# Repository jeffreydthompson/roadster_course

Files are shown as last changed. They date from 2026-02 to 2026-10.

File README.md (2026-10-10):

# Open Roadster

An open source remote control car — mechanical designs, circuit schematics, firmware, and software all in one place.

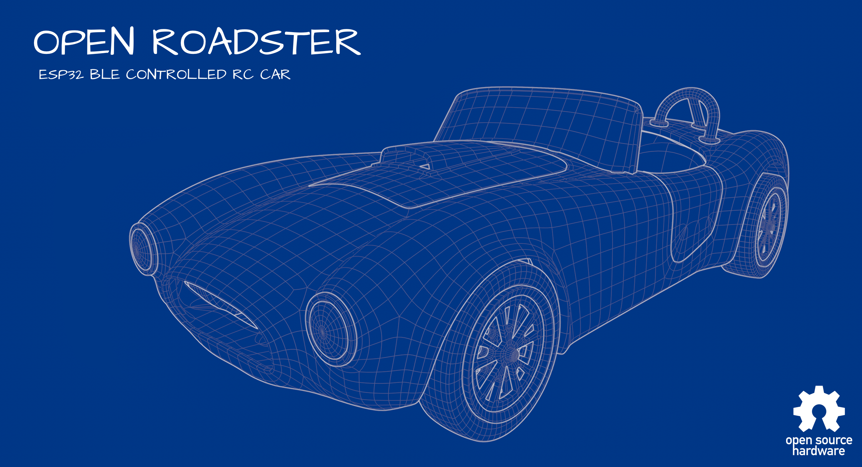
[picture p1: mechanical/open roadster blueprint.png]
Open Roadster Blueprint


## Overview

The Open Roadster is a fully open source RC car project covering every layer of the build:

- **Mechanical** — 3D-printable chassis and drivetrain in FreeCAD, body designed in Blender
- **Circuit** — custom 4-layer controller PCB designed in EasyEDA
- **Firmware** — ESP32-S3 motor, steering, and battery monitoring over Bluetooth LE
- **Software** — iOS remote control app (BLE)

## Repository Structure

```
├── mechanical/
│   ├── freecad/
│   │   ├── OpenRoadster.FCStd      # full chassis assembly, parts in position
│   │   ├── Printed Parts/          # one file per 3D-printed part
│   │   ├── Sheet Metal Parts/      # chassis base: model, flat-pattern DXF, bent STEP
│   │   └── Purchased Parts/        # motors, servo, bearing, screws, PCB
│   ├── stl/                        # ready-to-print STLs of the printed parts
│   ├── roadster.blend              # Blender body model
│   ├── open roadster blueprint.png
│   └── blueprints/                 # front, back, side, top views
├── code/
│   ├── app/ios/RoadsterRemote/     # iOS remote control app (SwiftUI + CoreBluetooth)
│   └── firmware/
│       ├── esp-flash.sh            # compile/upload helper (arduino-cli)
│       └── roadster_ctrl/          # main car firmware
└── circuits/
    ├── RCcar_schematic.pdf         # all schematic sheets
    ├── kicad/                      # KiCad 10 project (schematic + PCB), ported from EasyEDA
    ├── fabrication/                # Gerbers, BOM, pick-and-place for JLCPCB (from KiCad)
    └── easyeda/                    # original EasyEDA Standard source (schematic + PCB)
        └── fabrication/            # archived order files exported from EasyEDA
```

## Hardware

| Component | Details |
|---|---|
| Microcontroller | ESP32-S3 |
| Steering | Servo on GPIO 45 (333 Hz, 900–2100 µs, center 1520 µs) |
| Left drive motor | DRV8833 on GPIO 6 / 5 (sleep 11, fault 7) |
| Right drive motor | DRV8833 on GPIO 39 / 40 (sleep 38, fault 34) |
| Fuel gauge | MAX17048 over I2C (SDA 8, SCL 9) |
| Front light (headlights, `F.LED`) | GPIO 42, PWM |
| Rear light (tail / brake, `B.LED`) | GPIO 41, PWM |
| Power source (TPS2116 `ST`) | GPIO 26 — HIGH on USB power, LOW on battery |

All pins are defined at the top of `code/firmware/roadster_ctrl/roadster_ctrl.ino`. Motor direction is corrected in software with `setInverted(true)` in the same file — if a wheel spins the wrong way, that's the line to change.

## Getting Started

### Firmware

1. Install [arduino-cli](https://arduino.github.io/arduino-cli/) (or the [Arduino IDE](https://www.arduino.cc/en/software))
2. Install the ESP32 board support (`esp32:esp32`, tested with 3.3.x)
3. Install the libraries: `arduino-cli lib install ESP32Servo "Adafruit MAX1704X"`
4. Compile and upload:

```sh
cd code/firmware
./esp-flash.sh compile roadster_ctrl
./esp-flash.sh upload roadster_ctrl /dev/cu.usbmodem1101   # your port; see `arduino-cli board list`
```

The board target is set at the top of `esp-flash.sh` (`esp32:esp32:esp32s3`). If you use the Arduino IDE instead, open `code/firmware/roadster_ctrl/roadster_ctrl.ino` and select an ESP32S3 board.

### Driving the car

The car advertises over Bluetooth LE as `Open Roadster` and exposes two services:

| Service | UUID | Purpose |
|---|---|---|
| Nordic UART | `6E400001-B5A3-F393-E0A9-E50E24DCCA9E` | Control |
| ↳ RX (write) | `6E400002-B5A3-F393-E0A9-E50E24DCCA9E` | Control packets / commands |
| ↳ TX (notify) | `6E400003-B5A3-F393-E0A9-E50E24DCCA9E` | Feedback for single-character commands |
| Battery | `180F` | Standard Bluetooth battery service |
| ↳ Battery Level | `2A19` | 0–100 %, from the MAX17048 |
| ↳ Power Source | `8FDDF80E-8D10-4B50-9466-FCE56AF3B124` | 1 = on USB power (battery charging), 0 = on battery; notifies on change |

**Control packet** (what the iOS app sends) — 5 bytes, little-endian:

| Bytes | Type | Field | Range |
|---|---|---|---|
| 0–1 | `int16` | steering | -100 (left) … 100 (right) |
| 2–3 | `int16` | throttle | -255 (reverse) … 255 (forward) |
| 4 | `uint8` | headlight | 0 = off, 1 = on |

**Single-character commands** — writing one byte to RX also works, which makes it easy to test with a generic BLE UART app (nRF Connect, Bluefruit Connect):

| Command | Action |
|---|---|
| `f` | Forward, full speed |
| `b` | Backward, 25% speed |
| `s` | Stop |
| `l` / `r` / `c` | Steer left / right / center |

The same commands work over USB serial (115200 baud) when `ENABLE_SERIAL` is set to `true` in `roadster_ctrl.ino` (it is off by default).

As a safety failsafe, the motors stop automatically if the Bluetooth connection drops.

**Lights:** the headlight flag in the control packet turns on the front light, and the rear light glows as a tail light. The rear light goes to full brightness as a brake light when the throttle is released or drops sharply (held for 0.8 s), and stays on while reversing. Brightness levels and timing are constants at the top of `LightsModule.h`.

### iOS App

1. Open `code/app/ios/RoadsterRemote/RoadsterRemote.xcodeproj` in Xcode
2. In the project settings, under **Signing & Capabilities**, select your own **Team** (or create a free Apple Developer account)
3. Change the **Bundle Identifier** to one of your own (e.g., `com.yourname.RoadsterRemote`). Bundle IDs are unique per Apple account, so the default `org.openroadster.RoadsterRemote` may already be taken
4. Build and run on your device

On launch the app scans for nearby cars and lists every Open Roadster in range with its signal strength. Tap one to connect. Tap the connection indicator any time to switch cars or disconnect. The app drops back to Park whenever the connection is lost.

### Circuit board

The controller is a 4-layer, 60 × 40 mm board built around an **ESP32-S3-MINI-1-N8**. On board:

| Function | Part |
|---|---|
| Microcontroller (Wi-Fi + BLE) | ESP32-S3-MINI-1-N8 |
| Motor drivers (one per rear wheel) | 2× DRV8833 |
| Battery charger (single-cell LiPo, via USB-C) | MCP73831 |
| Fuel gauge | MAX17048 |
| 3.3 V supply (buck-boost) | TPS63001 |
| USB / battery power switchover | TPS2116 |
| USB-to-serial for programming | CP2102N |
| Connectors | USB-C, battery (PH2.0), 2× motor, servo, front + rear LED |

Files in `circuits/`:

- `RCcar_schematic.pdf` — the full schematic (Sheet 1, Power, Motor Control, LED Drivers, USB Programmer); no software needed
- `kicad/` — the full design as a [KiCad](https://www.kicad.org/) 10 project; open `RCcar.kicad_pro` (see notes below)
- `fabrication/` — **the files to order with**, generated from the KiCad project in JLCPCB's format: `RCcar_kicad_gerber.zip`, `RCcar_bom_jlcpcb.csv`, `RCcar_cpl_jlcpcb.csv`
- `easyeda/` — the original EasyEDA Standard source. In EasyEDA, use **File → Open → EasyEDA Source** to open `RCcar_schematic.json` and `RCcar_pcb.json`
- `easyeda/fabrication/` — archived order files exported from EasyEDA (`RCcar_gerber.zip`, `RCcar_bom.csv`, `RCcar_pick_and_place.csv`), kept for reference

The board passes EasyEDA's design rule check with no errors, and all nets are routed.

**About the KiCad port.** The KiCad project was imported from the EasyEDA source and checked against it:

- Schematic and board agree on every connection (KiCad's schematic parity check finds no split or merged nets; remaining parity notes are naming differences from the import).
- Design rules match EasyEDA's (0.152 mm minimum clearance, 0.254 mm tracks); DRC reports no clearance errors and no unconnected items.
- KiCad fills copper pours slightly differently from EasyEDA, so 14 short tracks (0.2 mm) were added where KiCad's fill couldn't reach a few fine-pitch pins that EasyEDA's pour connected (around U1, U3, U5, U6, U7 and R2).
- KiCad's Gerbers match EasyEDA's copper to within about 1% per layer; the differences are pour edges and thermal spokes around pads.
- The project is self-contained: all symbols and footprints live in project libraries (`RCcar.kicad_sym`, `RCcar.pretty/`), registered in the project's `sym-lib-table` and `fp-lib-table`.
- Remaining DRC/ERC items are left visible on purpose. They are cosmetic or come from the import: courtyard overlaps from the tight placement, EasyEDA silkscreen touching pads, footprints that differ from their library copy by rounding or 3D model, and EasyEDA symbols whose pin types trigger "not driven" and pin-type warnings.
- 3D models aren't included yet; the 3D viewer will show bare footprints.

**Ordering from JLCPCB.** Upload the Gerber zip for bare boards (4 layers, 60 × 40 mm). For assembly, add the BOM and CPL (pick-and-place) files; every part has an LCSC part number. Parts are on both sides, so choose two-sided assembly. Always check part rotations in JLCPCB's assembly preview before paying.

The KiCad order files were checked against the EasyEDA ones: the same 91 parts with the same LCSC numbers, identical positions, sides and rotations, and copper within about 1% per layer (pour edges). KiCad also opens the solder mask around the bare mounting and locating holes. The EasyEDA set is what the original boards were made from. The KiCad set in `fabrication/` is the one to use; KiCad is now where the design is maintained.

### Mechanical

**Chassis, steering, and wheels** are in [FreeCAD](https://www.freecad.org/) (1.0 or newer) under `mechanical/freecad/`:

- `OpenRoadster.FCStd` — the complete chassis assembly with every part in position
- `Printed Parts/` — one file per printed part, for editing. Ready-to-print STLs are in `mechanical/stl/` (exported at 0.01 mm tolerance, in mm)
- `Sheet Metal Parts/` — the chassis base, made by a sheet metal shop rather than printed (see below)
- `Purchased Parts/` — models of the off-the-shelf components, for fit checks

| Purchased part | Qty |
|---|---|
| N20 DC gear motor (`or.n20.dc.motor`) | 2 |
| D1802MG micro servo (`or.d1802mg.servo`) | 1 |
| Front wheel bearing (`or.bearing.front`) | 2 |
| Hub screw (`or.hubscrew`) | 4 |
| Controller PCB (`PCB`) | 1 |

**Sheet metal chassis base** (`or.sheetmetal.base`) — 0.8 mm steel, flat blank 100.6 × 167.0 mm, 9 bends. Send a fabrication service (SendCutSend, OSH Cut, JLCCNC, etc.) both files:

- `or.sheetmetal.base.flat.dxf` — flat pattern in mm; outline and holes on layer `CUT`, bend lines on layer `BEND`
- `or.sheetmetal.base.step` — the bent part, so the shop can confirm bend directions and angles

The parts were converted from the original Onshape model as solid bodies, so they don't carry the parametric feature history. They can be measured, modified, and re-exported, but not edited by changing the original sketches.

**Body:** open `mechanical/roadster.blend` in [Blender](https://www.blender.org/) and export STL files for printing. Refer to the blueprints for assembly dimensions.

## License

- Code (`code/`) — [MIT](LICENSE)
- Hardware and mechanical designs (`mechanical/`, `circuits/`) — [CC BY 4.0](https://creativecommons.org/licenses/by/4.0/)

See [LICENSE](LICENSE) for details.

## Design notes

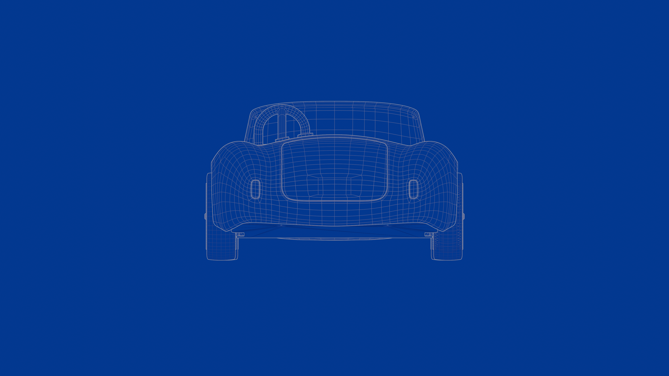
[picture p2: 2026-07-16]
mechanical/blueprints/back.png

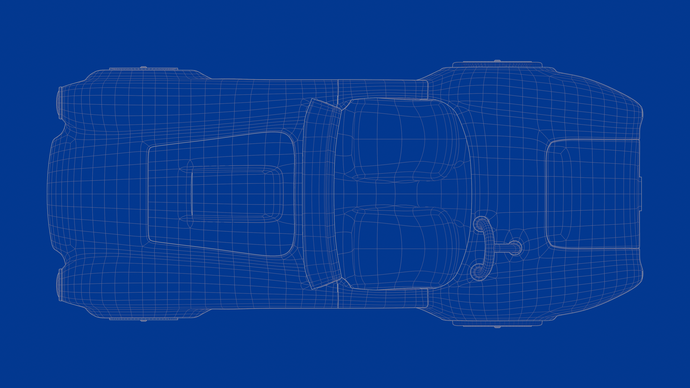
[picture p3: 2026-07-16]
mechanical/blueprints/top.png

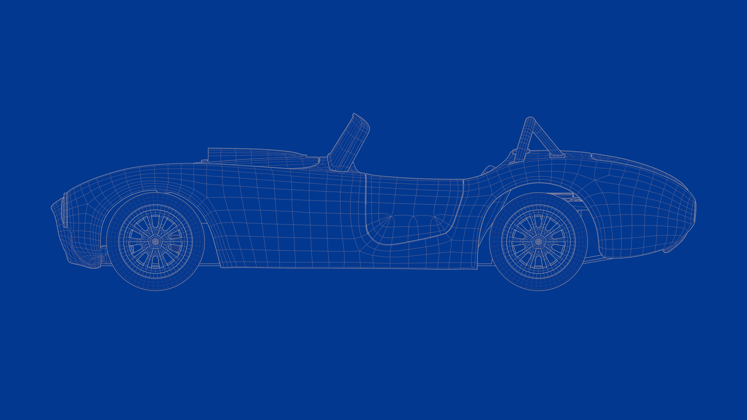
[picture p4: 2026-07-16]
mechanical/blueprints/side.png

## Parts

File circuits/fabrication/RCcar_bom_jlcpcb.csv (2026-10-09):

Comment | Designator | Footprint | LCSC Part #
SM02B-SRSS-TB (LF)(SN) | B.LED,F.LED | CONN-SMD_2P-P1.00_SM02B-SRSS-TB-LF-SN | C160402
PH2.0-2PWB | BATTERY | CONN-SMD_2P-P2.00_PH2.0-SPWB | C47647
TS-1088-AR02016 | BOOT,EN | SW-SMD_L3.9-W3.0-P4.45 | C720477
4.7uF | C1 | C0402 | C23733
22uF | C2 | C0805 | C45783
4.7uF | C3,C4 | C0805 | C1779
22uF | C5,C25,C34 | C1206 | C7472972
100nF | C6,C18,C20,C22,C23 | C0402_NEW | C1525
10uF | C7,C8,C9 | C0603 | C3039698
100nF | C10 | C0402_v2 | C1525
100nF | C11,C27,C32 | C0603 | C66501
2.2uF | C26,C33 | C0603 | C100082
10nF | C28,C31 | C0603 | C519406
100nF | C29,C30 | C0603 | C14663
0805G (Green) | CHARGED | LED0805-R-RD | C2297
17-21SUYC/TR8 | CHARGING | LED0805-R-RD | C2296
SP0503BAHTG | D3 | SOT-143_L2.9-W1.3-P1.92-LS2.3-BR | C7074
S2B-ZR-SM4A-TF(LF)(SN) | L.MOTOR,R.MOTOR | CONN-SMD_S2B-ZR-SM4A | C265329
2.2uH | L1 | IND-SMD_L3.0-W3.0_FNR30XXS | C370424
FC-2012HRK-620D | POWER | LED0805-R-RD | C84256
SI2305CDS | Q1 | SOT-23-3_L2.9-W1.6-P1.90-LS2.8-BR | C5182095
2SC2712-GR,LF(T | Q3,Q4,Q7,Q8 | SOT-23-3_L2.9-W1.6-P1.90-LS2.8-BR | C83447
SS8050-G | Q10,Q11 | SOT-23-3_L2.9-W1.6-P1.90-LS2.8-BR | C164886
5.1kΩ | R1,R5,R6,R9 | R0402 | C25905
10kΩ | R2,R3,R8,R14,R16,R19,R37,R38,R41 | R0402 | C25744
100Ω | R4 | R0402 | C25076
470Ω | R7,R10,R11 | R0603 | C23179
4.7kΩ | R12,R13 | R0402 | C25900
100Ω | R15,R17,R18,R20 | R0402 | C106232
22Ω | R21,R23 | R0603 | C23345
1kΩ | R22,R24 | R0603 | C161809
100kΩ | R25 | R0603 | C25803
1kΩ | R31 | R0402 | C11702
47.5kΩ | R32 | R0402 | C25896
22.1kΩ | R33 | R0402 | C43473
22Ω | R35 | R0402 | C25092
0Ω | R39,R40 | R0402 | C17168
HCZZ0323-3 | SERVO | CONN-SMD_3P-P1.50_HCZZ0323-3 | C7433559
MS-12D08G3.5 | SW2 | SW-TH_MS-12D08G3.5 | C2939255
ESP32-S3-MINI-1-N8 | U1 | BULETM-SMD_ESP32-S3-MINI-1-N8 | C2913206
TPS2116DRLR | U3 | SOT-583-8_L2.1-W1.6-P0.50-LS1.6-BL | C3235557
50mΩ | U4,U11 | R1206 | C7467249
TPS63001DRCR | U5 | VSON-10_L3.0-W3.0-P0.50-TL-EP_TPS62410DRCR | C28060
CP2102N-A02-GQFN28R | U6 | QFN-28_L5.0-W5.0-P0.50-TL-EP3.3 | C964632
MAX17048G+T10 | U7 | TDFN-8_L2.0-W2.0-P0.50-BL-EP1.2 | C2682616
DRV8833RTYR | U8,U10 | QFN-16_L4.0-W4.0-P0.65-TL-EP2.6 | C154936
MCP73831T-2ACI/OT | U9 | SOT-23-5_L3.0-W1.7-P0.95-LS2.8-BR | C424093
TYPE-C 16PIN 2MD(073) | USB | USB-C-SMD_TYPE-C-6PIN-2MD-073 | C2765186

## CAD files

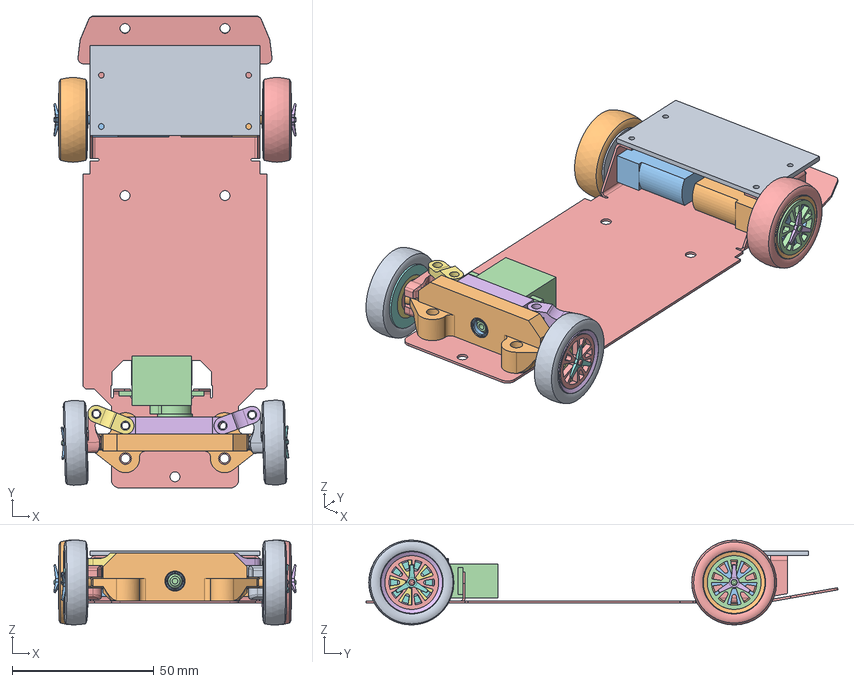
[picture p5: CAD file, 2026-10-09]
mechanical/freecad/OpenRoadster.FCStd
85.4 x 166.7 x 30.0 mm
PCB
or.n20.dc.motor
or.n20.dc.motor001
or.d1802mg.servo
or.sheetmetal.base
or.linkage.rack
or.bearing.front
or.bearing.front001
or.steeringknuckle.left
or.linkage.frame
or.pinion.bushing
or.linkage.pinion
or.steeringknuckle.right
or.linkage.arm
or.linkage.arm001
or.rim.front
or.tire.front
or.hub.front
or.hubscrew
or.hubcap
or.hubcap001
or.rim.front001
or.hub.front001
or.hubscrew001
or.tire.front001
or.rim.rear
or.hub.rear
or.hubcap002
or.tire.rear
or.hubscrew002
or.hub.rear001
or.hubcap003
or.rim.rear001
or.tire.rear001
or.hubscrew003

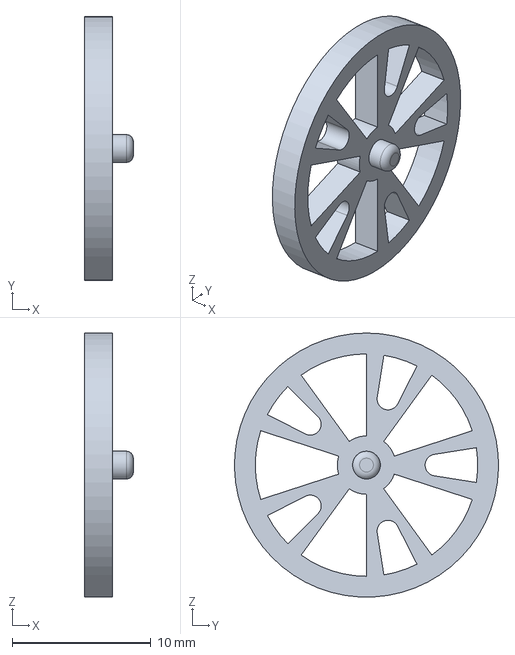
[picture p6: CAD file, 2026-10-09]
mechanical/freecad/Printed Parts/or.hubcap.FCStd
3.50 x 19.0 x 19.0 mm

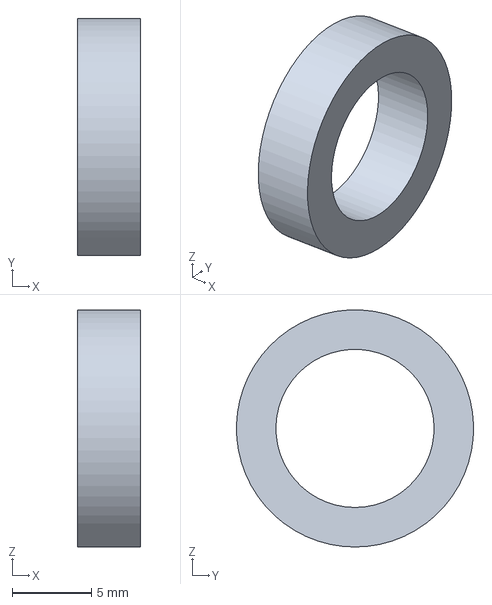
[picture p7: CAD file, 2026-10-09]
mechanical/freecad/Purchased Parts/or.bearing.front.FCStd
4.00 x 15.0 x 15.0 mm

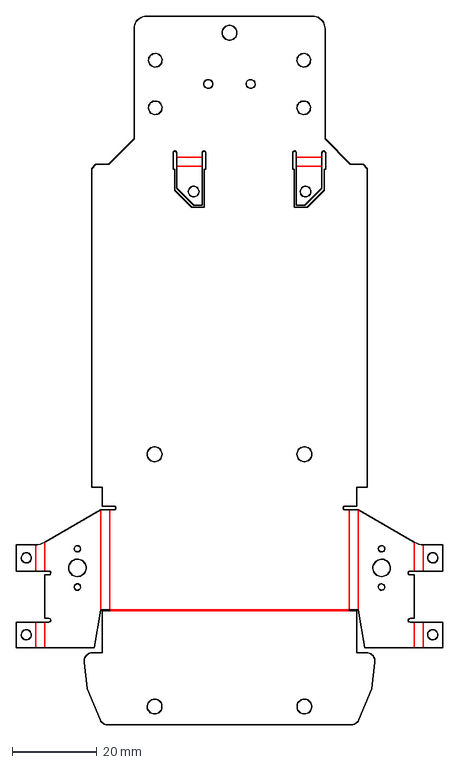
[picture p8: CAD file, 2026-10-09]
mechanical/freecad/Sheet Metal Parts/or.sheetmetal.base.flat.dxf
100.5 x 167.0 mm

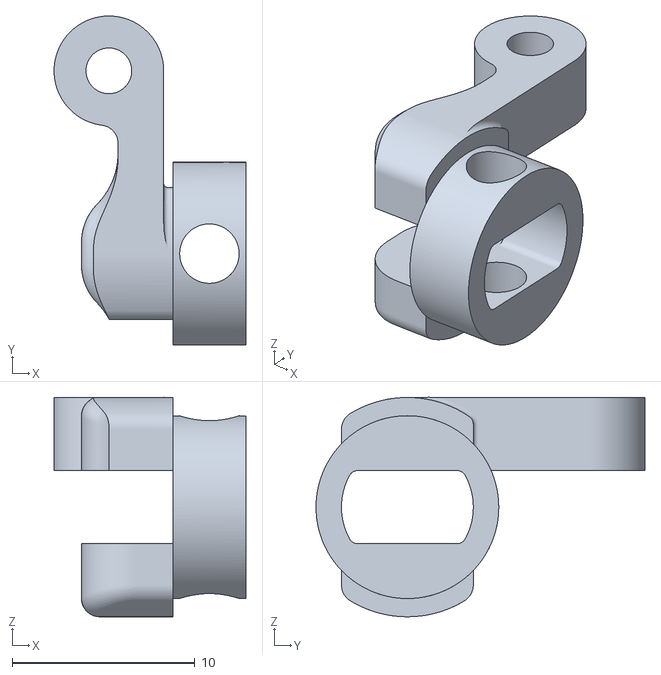
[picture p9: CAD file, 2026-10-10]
mechanical/stl/or.steeringknuckle.left.stl
10.5 x 18.0 x 12.0

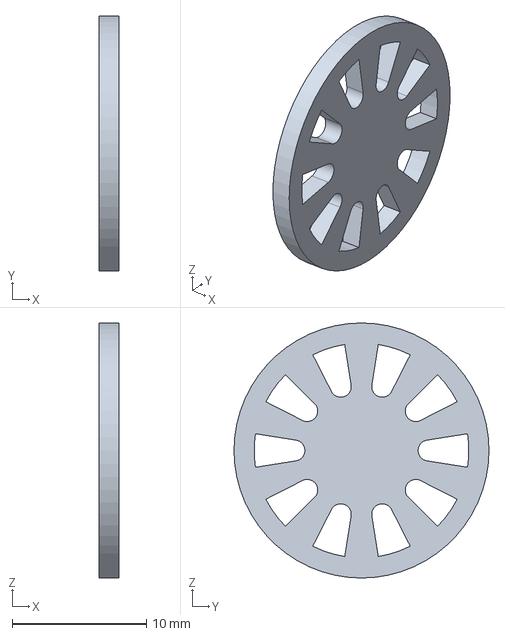
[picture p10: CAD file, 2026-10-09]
mechanical/freecad/Printed Parts/or.hub.front.FCStd
1.50 x 19.0 x 19.0 mm

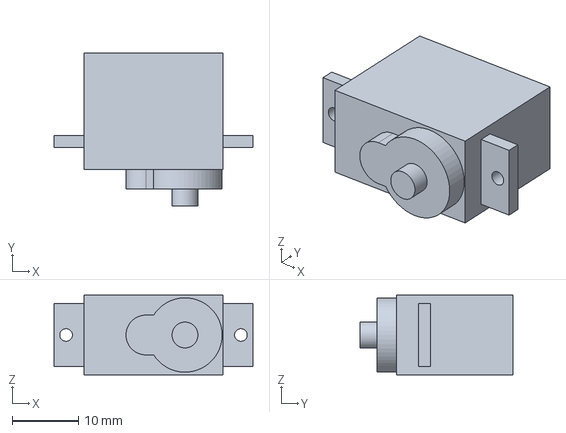
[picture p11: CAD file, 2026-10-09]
mechanical/freecad/Purchased Parts/or.d1802mg.servo.FCStd
30.0 x 23.0 x 12.0 mm

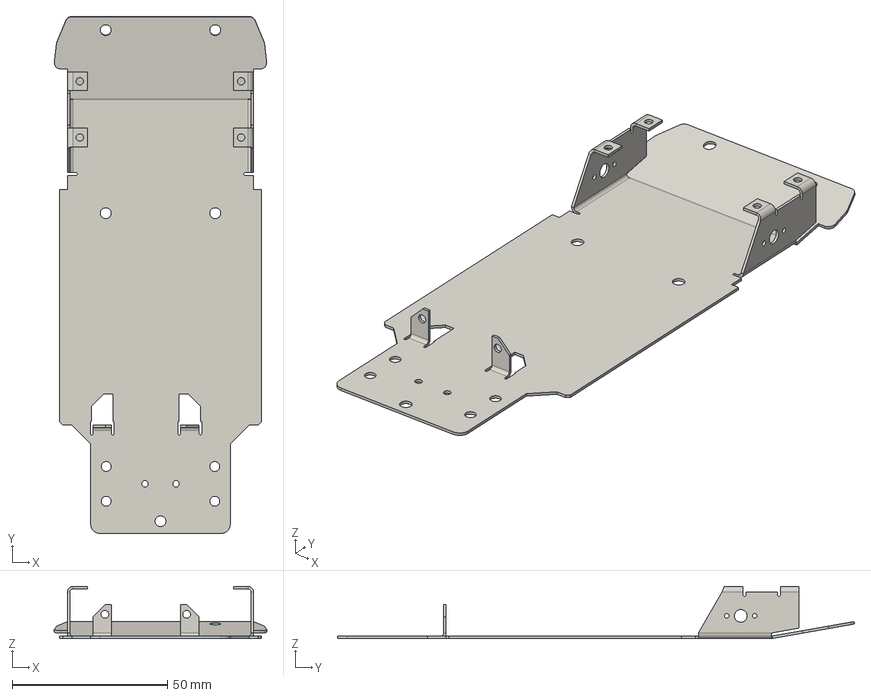
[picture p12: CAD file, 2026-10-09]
mechanical/freecad/Sheet Metal Parts/or.sheetmetal.base.step
68.5 x 166.7 x 16.8 mm

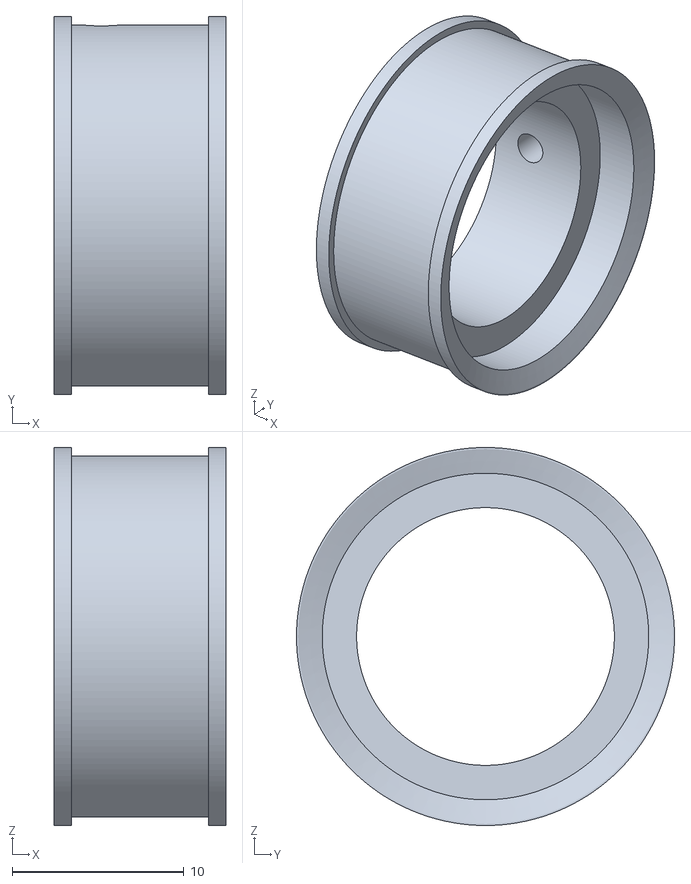
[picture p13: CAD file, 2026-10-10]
mechanical/stl/or.rim.rear.stl
10.0 x 22.0 x 22.0

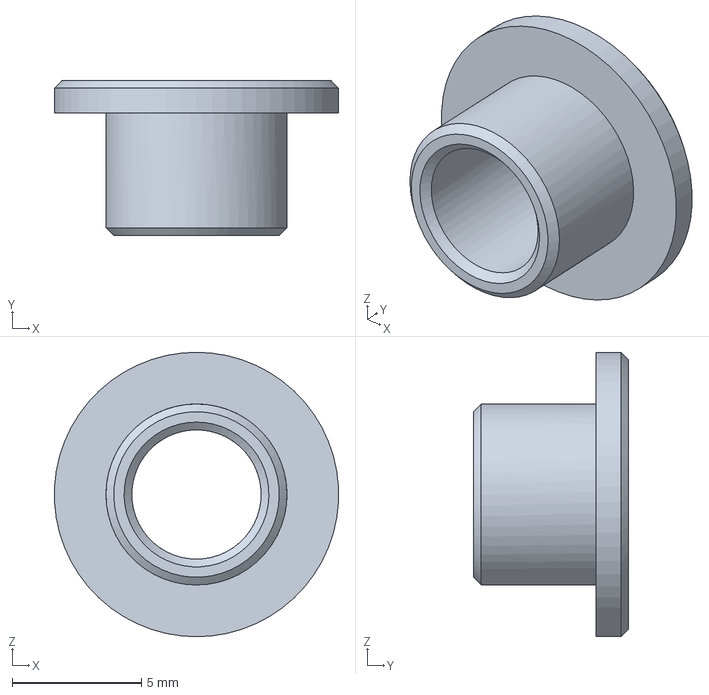
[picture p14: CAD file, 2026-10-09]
mechanical/freecad/Printed Parts/or.pinion.bushing.FCStd
11.0 x 6.00 x 11.0 mm

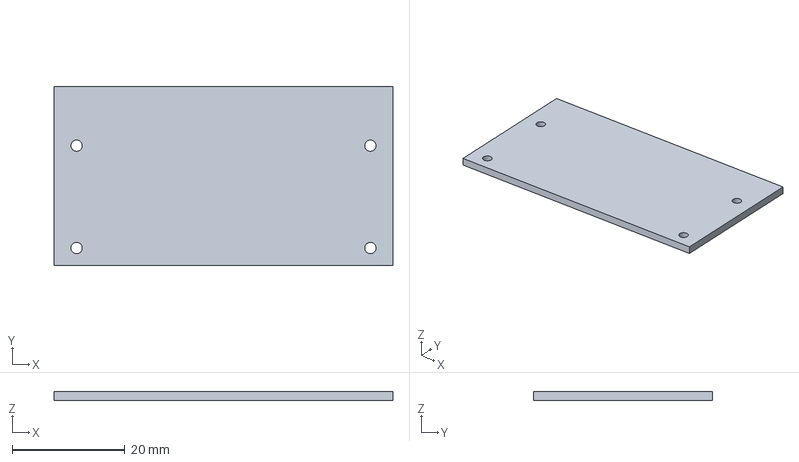
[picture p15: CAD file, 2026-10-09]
mechanical/freecad/Purchased Parts/PCB.FCStd
60.0 x 31.7 x 1.60 mm

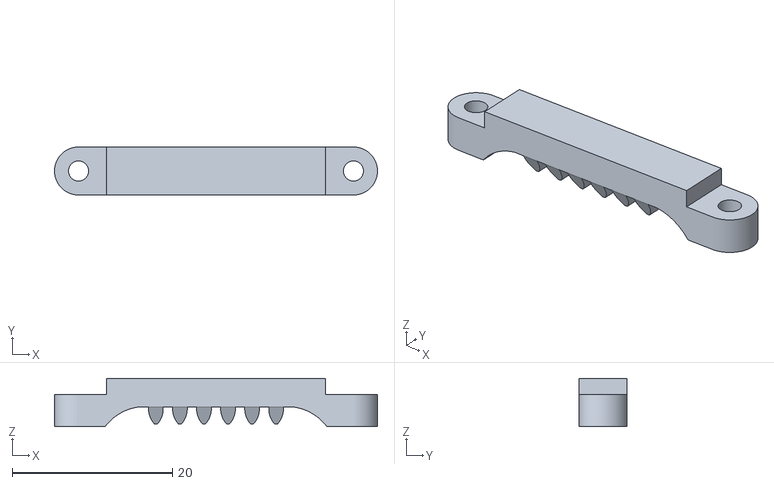
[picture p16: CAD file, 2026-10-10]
mechanical/stl/or.linkage.rack.stl
40.3 x 6.00 x 6.00

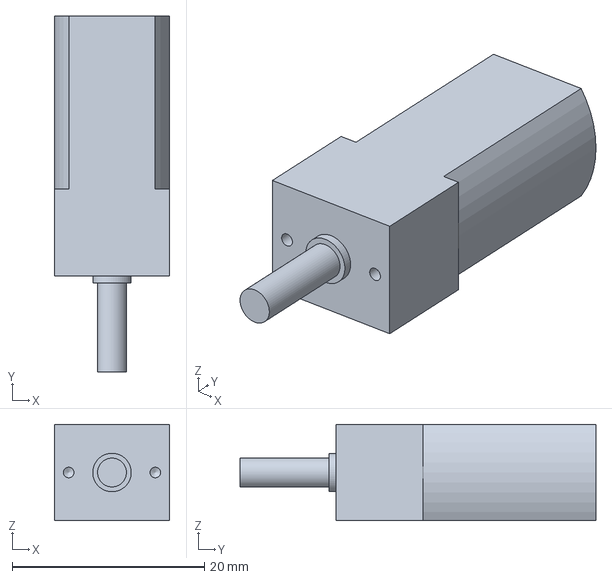
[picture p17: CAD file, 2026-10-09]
mechanical/freecad/Purchased Parts/or.n20.dc.motor.FCStd
12.0 x 37.0 x 10.0 mm

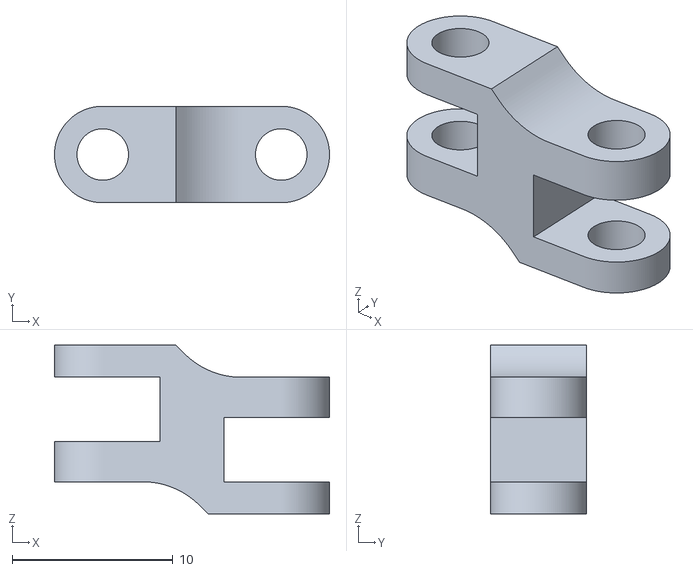
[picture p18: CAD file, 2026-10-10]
mechanical/stl/or.linkage.arm.stl
17.1 x 6.00 x 10.5

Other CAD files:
mechanical/freecad/Printed Parts/or.linkage.rack.FCStd
mechanical/freecad/Printed Parts/or.linkage.arm.FCStd
mechanical/stl/or.linkage.frame.stl
mechanical/freecad/Printed Parts/or.rim.rear.FCStd
mechanical/freecad/Printed Parts/or.hub.rear.FCStd
mechanical/freecad/Printed Parts/or.linkage.frame.FCStd
mechanical/freecad/Printed Parts/or.linkage.pinion.FCStd
mechanical/freecad/Printed Parts/or.rim.front.FCStd
mechanical/freecad/Printed Parts/or.steeringknuckle.left.FCStd
mechanical/freecad/Printed Parts/or.steeringknuckle.right.FCStd
mechanical/freecad/Printed Parts/or.tire.front.FCStd
mechanical/freecad/Printed Parts/or.tire.rear.FCStd
mechanical/freecad/Purchased Parts/or.hubscrew.FCStd
mechanical/freecad/Sheet Metal Parts/or.sheetmetal.base.FCStd
mechanical/roadster.blend
mechanical/stl/or.hub.front.stl
mechanical/stl/or.hub.rear.stl
mechanical/stl/or.hubcap.stl
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

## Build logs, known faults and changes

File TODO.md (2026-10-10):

# TODO

## Battery protection

A pack left with the power switch on drains until the buck-boost gives up
(about 1.8 V), which kills the cell. Nothing on the Rev 2 board stops this.

### Firmware (Rev 2 boards)

- [ ] Low-battery cutoff: poll the MAX17048 cell voltage (already read every
      2 s in `BatteryModule`).
  - Below ~3.3 V under load: stop the motors and flash the lights as a warning.
  - Below ~3.2 V: stop the motors and put the ESP32 into deep sleep.
  - This is only partial protection. The servo, fuel gauge, regulator and
    motor drivers stay powered in sleep (estimated 1–5 mA, not yet measured),
    so it buys days, not months.
- [ ] Measure the actual idle current with the switch on (advertising, and in
      deep sleep) to know how long a forgotten car lasts.
- [ ] Report cell voltage over BLE alongside the percentage, since the
      MAX17048 % is unreliable until it has seen a charge/discharge cycle.

### Hardware (Rev 3 board)

- [ ] Add a battery protection IC (e.g. DW01A + FS8205A) between the
      BATTERY connector and VBATT, for hardware over-discharge, over-charge
      and short-circuit cutoff.
- [ ] Connect MAX17048 ALRT# to a GPIO (it's unconnected on Rev 2) so a low
      battery alert can wake the ESP32.
- [ ] Consider letting the ESP32 shut off the TPS63001 (its EN is currently
      tied to VIN through R4) or switch the servo supply, so firmware can do
      a real cutoff.

The power switch (SW2) itself is fine. It disconnects everything except the
MCP73831's VBAT pin (~0.25 µA) and the reverse-polarity FET, and charging
still works with it off.

## App / firmware

- [ ] Throttle range mismatch: the iOS app sends 0..100 with no reverse,
      the firmware expects −255..255. App full throttle is only ~40%.

## PCB (KiCad)

- [ ] Remaining DRC items: courtyard overlaps, CHARGED/CHARGING silk over SW2.
- [ ] 3D models for the footprints.

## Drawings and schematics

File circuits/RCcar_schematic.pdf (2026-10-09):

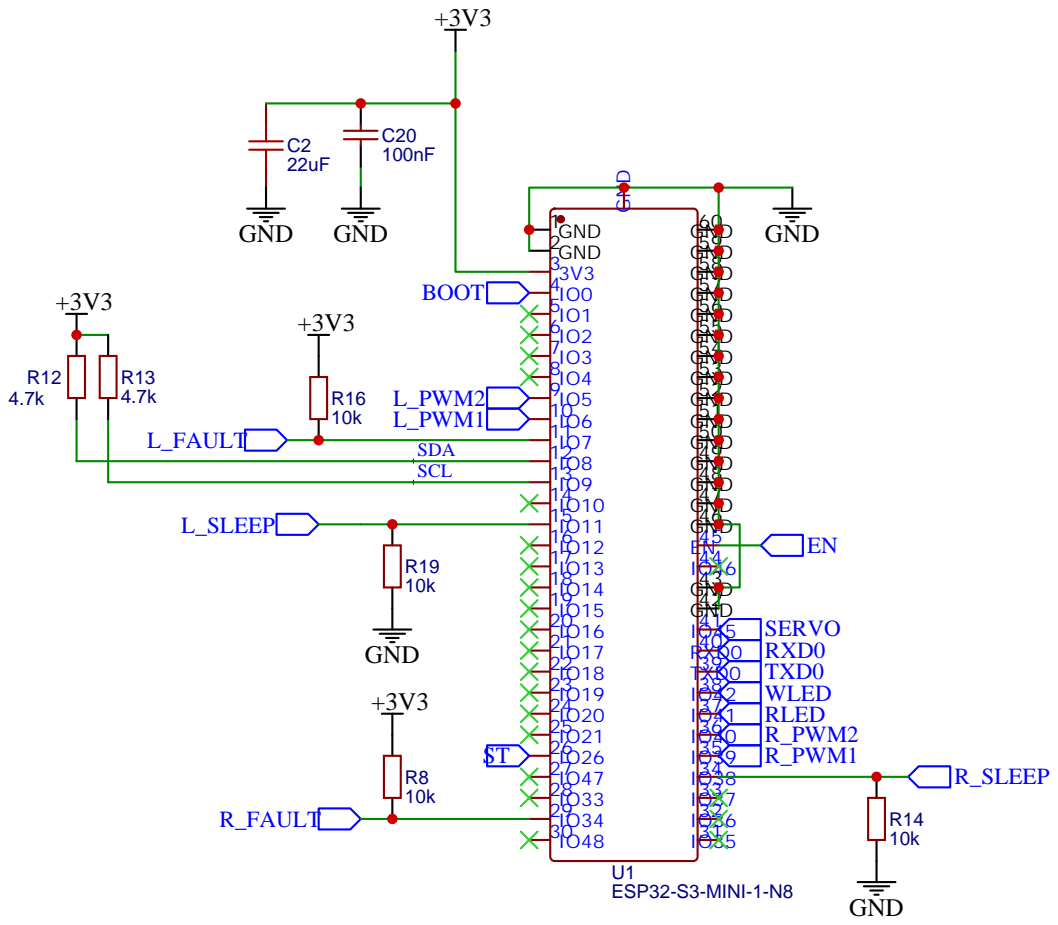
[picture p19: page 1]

Drawn By: Jeffrey Thompson

# CHARGE

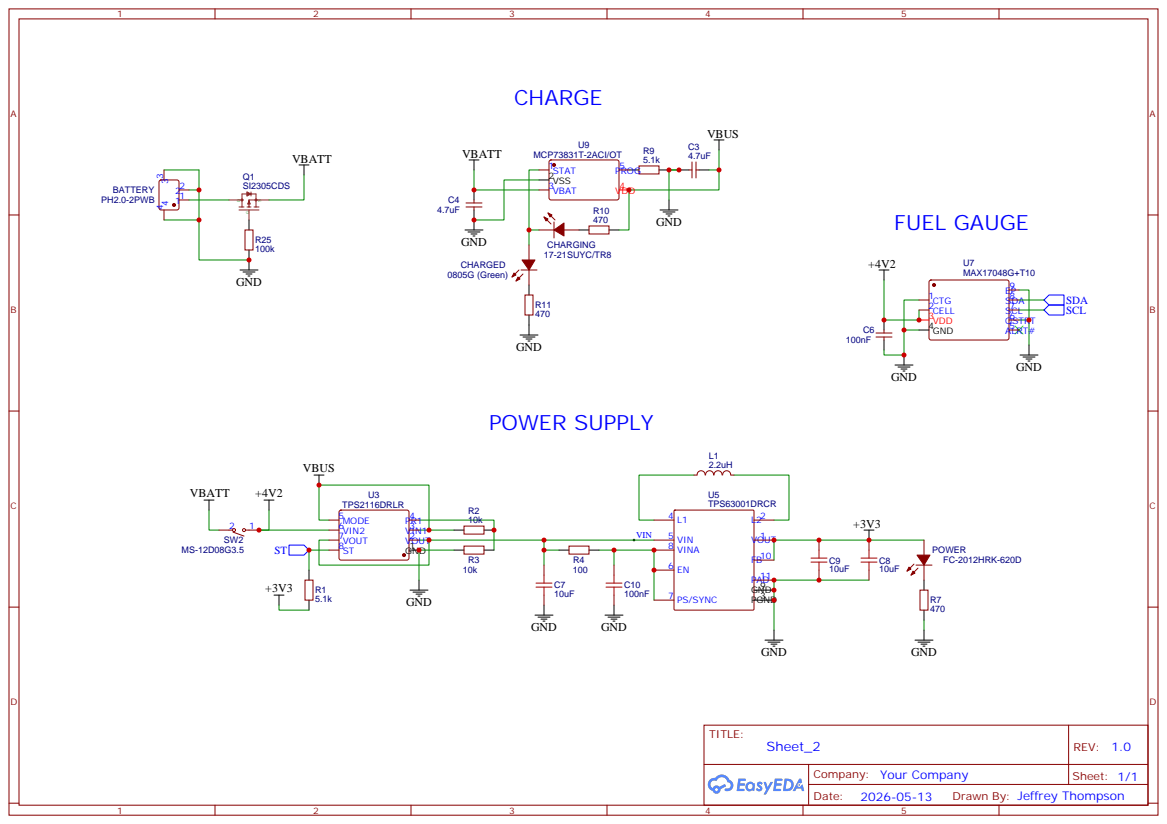
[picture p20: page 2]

# L MOTOR

# VM10 GND 11 VINT 12 AIN2 13 AIN1 14 nSLEEP 15 AOUT1 16 GND 17

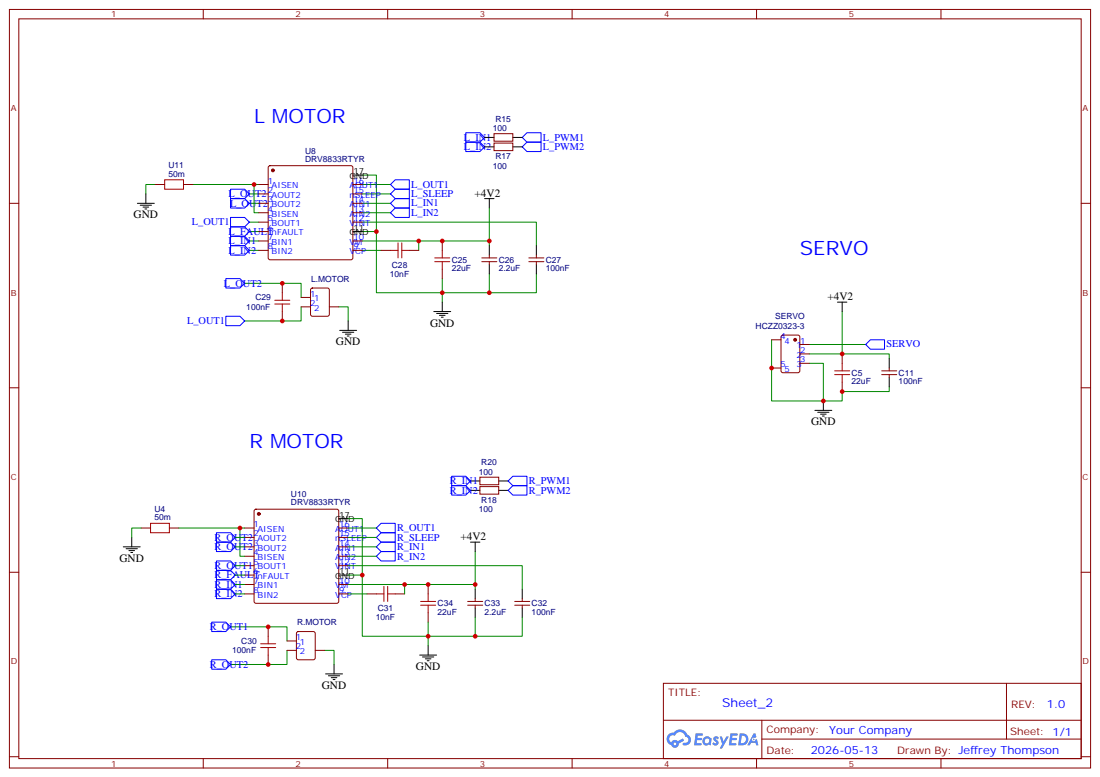
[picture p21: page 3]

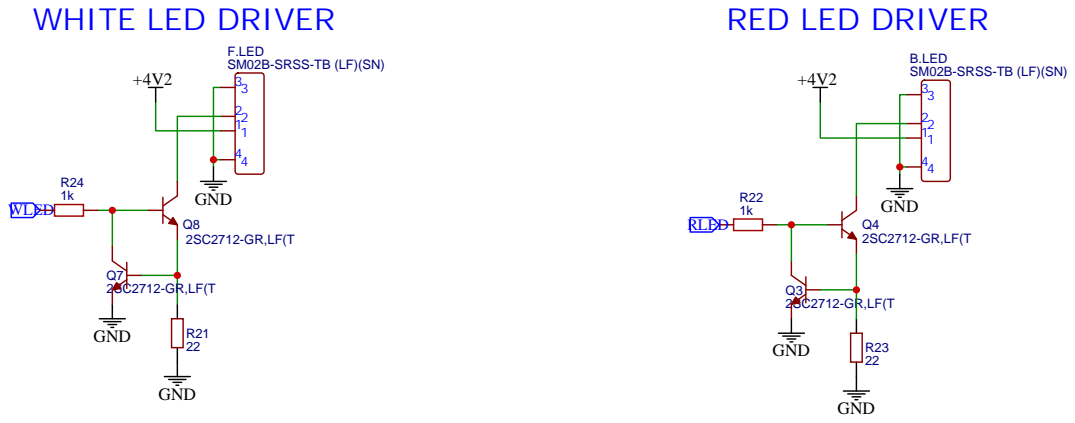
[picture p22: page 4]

# USB TO SERIAL CONVERTER

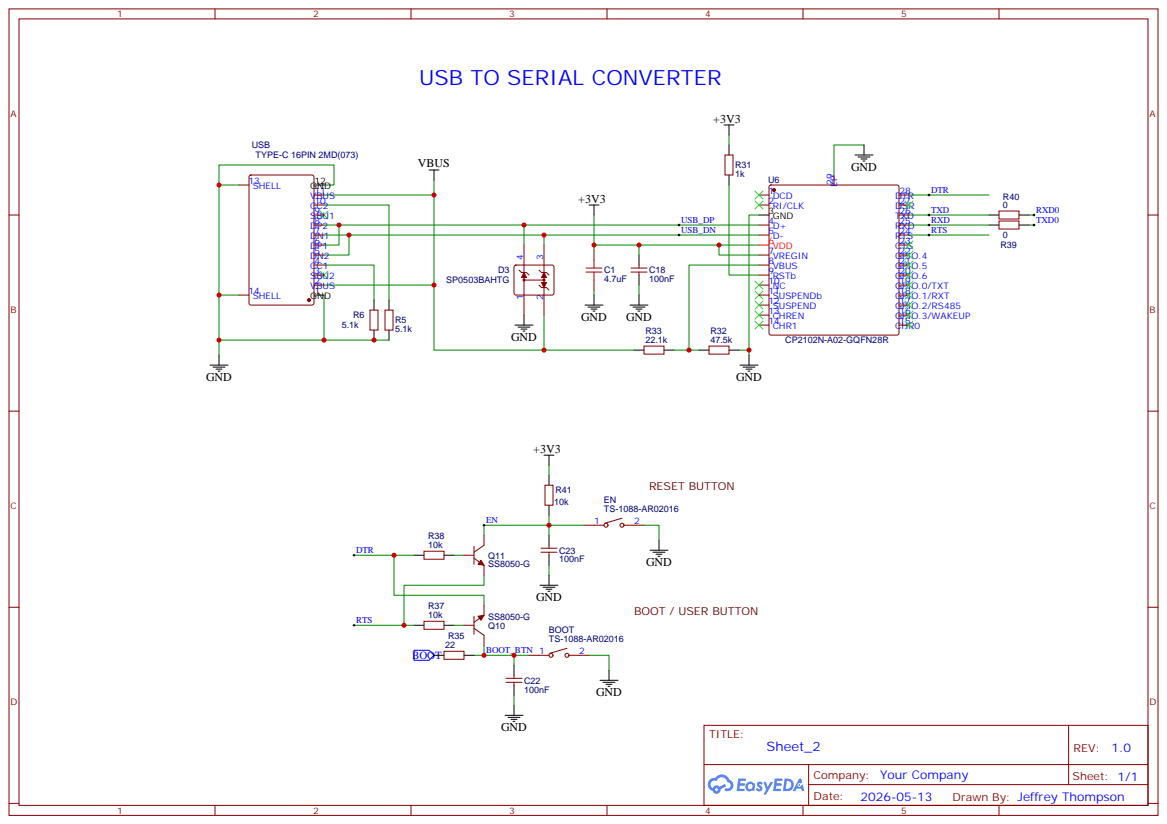
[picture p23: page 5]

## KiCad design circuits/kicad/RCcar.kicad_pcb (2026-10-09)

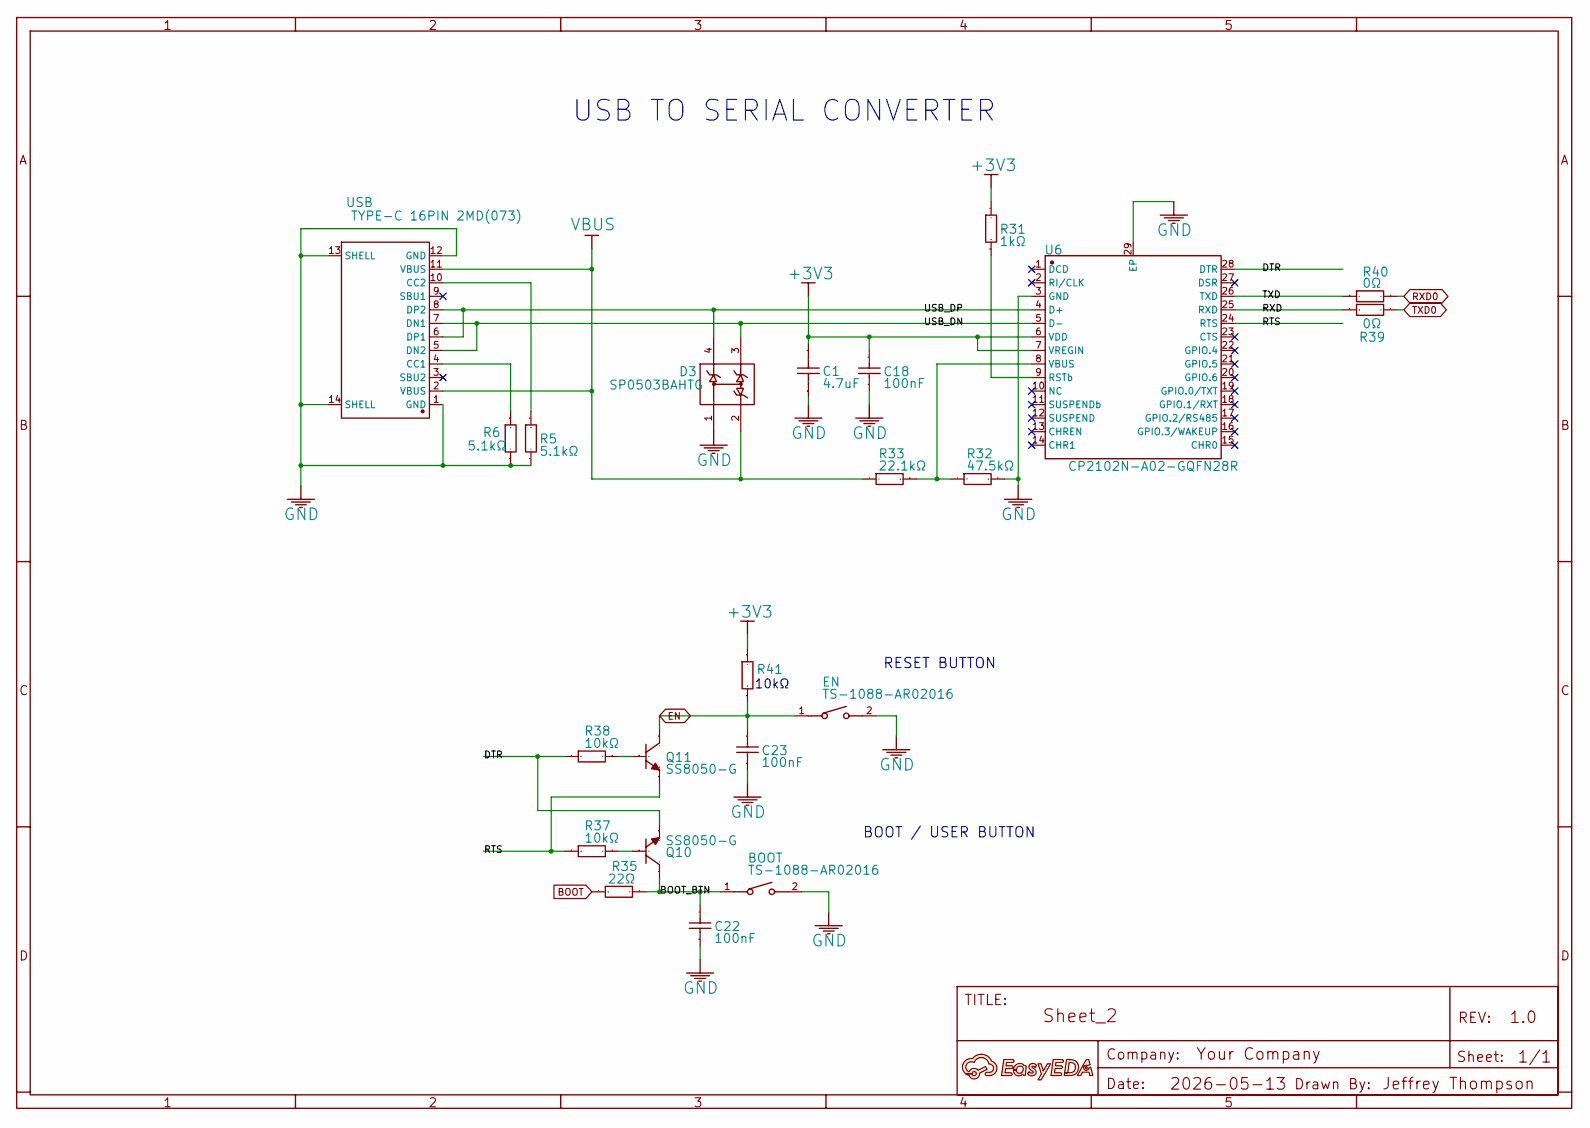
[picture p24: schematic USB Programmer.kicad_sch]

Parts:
A: A; Manufacturer Part ?
BOOT: TS-1088-AR02016; SW-SMD_L3.9-W3.0-P4.45; Manufacturer Part TS-1088-AR02016
C1: 4.7uF; C0402; Manufacturer Part CL05A475MP5NRNC
C18, C22, C23: 100nF; C0402_NEW; Manufacturer Part CL05B104KO5NNNC
D3: SP0503BAHTG; SOT-143_L2.9-W1.3-P1.92-LS2.3-BR; Manufacturer Part SP0503BAHTG
EN: TS-1088-AR02016; SW-SMD_L3.9-W3.0-P4.45; Manufacturer Part TS-1088-AR02016
Q10, Q11: SS8050-G; SOT-23-3_L2.9-W1.6-P1.90-LS2.8-BR; Manufacturer Part SS8050-G
R5, R6: 5.1kΩ; R0402; Manufacturer Part 0402WGF5101TCE
R31: 1kΩ; R0402; Manufacturer Part 0402WGF1001TCE
R32: 47.5kΩ; R0402; Manufacturer Part 0402WGF4752TCE
R33: 22.1kΩ; R0402; Manufacturer Part 0402WGF2212TCE
R35: 22Ω; R0402; Manufacturer Part 0402WGF220JTCE
R37, R38, R41: 10kΩ; R0402; Manufacturer Part 0402WGF1002TCE
R39, R40: 0Ω; R0402; Manufacturer Part 0402WGF0000TCE
U6: CP2102N-A02-GQFN28R; QFN-28_L5.0-W5.0-P0.50-TL-EP3.3; Manufacturer Part CP2102N-A02-GQFN28R
USB: TYPE-C 16PIN 2MD(073); USB-C-SMD_TYPE-C-6PIN-2MD-073; Manufacturer Part TYPE-C 16PIN 2MD(073)

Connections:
+3V3: C1.2, C18.2, R31.2, R41.2, U6.6 (VDD), U6.7 (VREGIN); also elsewhere on the board
/USB Programmer/BOOT_BTN: BOOT.1, C22.2, Q10.3 (C), R35.2
/USB Programmer/DTR: Q10.2 (E), R38.1, U6.28 (DTR)
/USB Programmer/RTS: Q11.2 (E), R37.1, U6.24 (RTS)
/USB Programmer/RXD: R39.1, U6.25 (RXD)
/USB Programmer/TXD: R40.1, U6.26 (TXD)
/USB Programmer/USB_DN: D3.3, U6.5 (D-), USB.5 (DN2), USB.7 (DN1)
/USB Programmer/USB_DP: D3.4, U6.4 (D+), USB.6 (DP1), USB.8 (DP2)
BOOT: R35.1; also elsewhere on the board
EN: C23.2, EN.1, Q11.3 (C), R41.1; also elsewhere on the board
GND: BOOT.2, C1.1, C18.1, C22.1, C23.1, D3.1, EN.2, R5.2, R6.2, R32.1, U6.3 (GND), U6.29 (EP), USB.1 (GND), USB.12 (GND), USB.13 (SHELL), USB.14 (SHELL); also elsewhere on the board
unnamed: Q10.1 (B), R37.2
unnamed: Q11.1 (B), R38.2
unnamed: R31.1, U6.9 (RSTb)
unnamed: R32.2, R33.1, U6.8 (VBUS)
unnamed: R6.1, USB.4 (CC1)
unnamed: R5.1, USB.10 (CC2)
RXD0: R40.2; also elsewhere on the board
TXD0: R39.2; also elsewhere on the board
VBUS: D3.2, R33.2, USB.2 (VBUS), USB.11 (VBUS); also elsewhere on the board

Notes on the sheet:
RESET BUTTON
10kΩ
BOOT / USER BUTTON
USB TO SERIAL CONVERTER

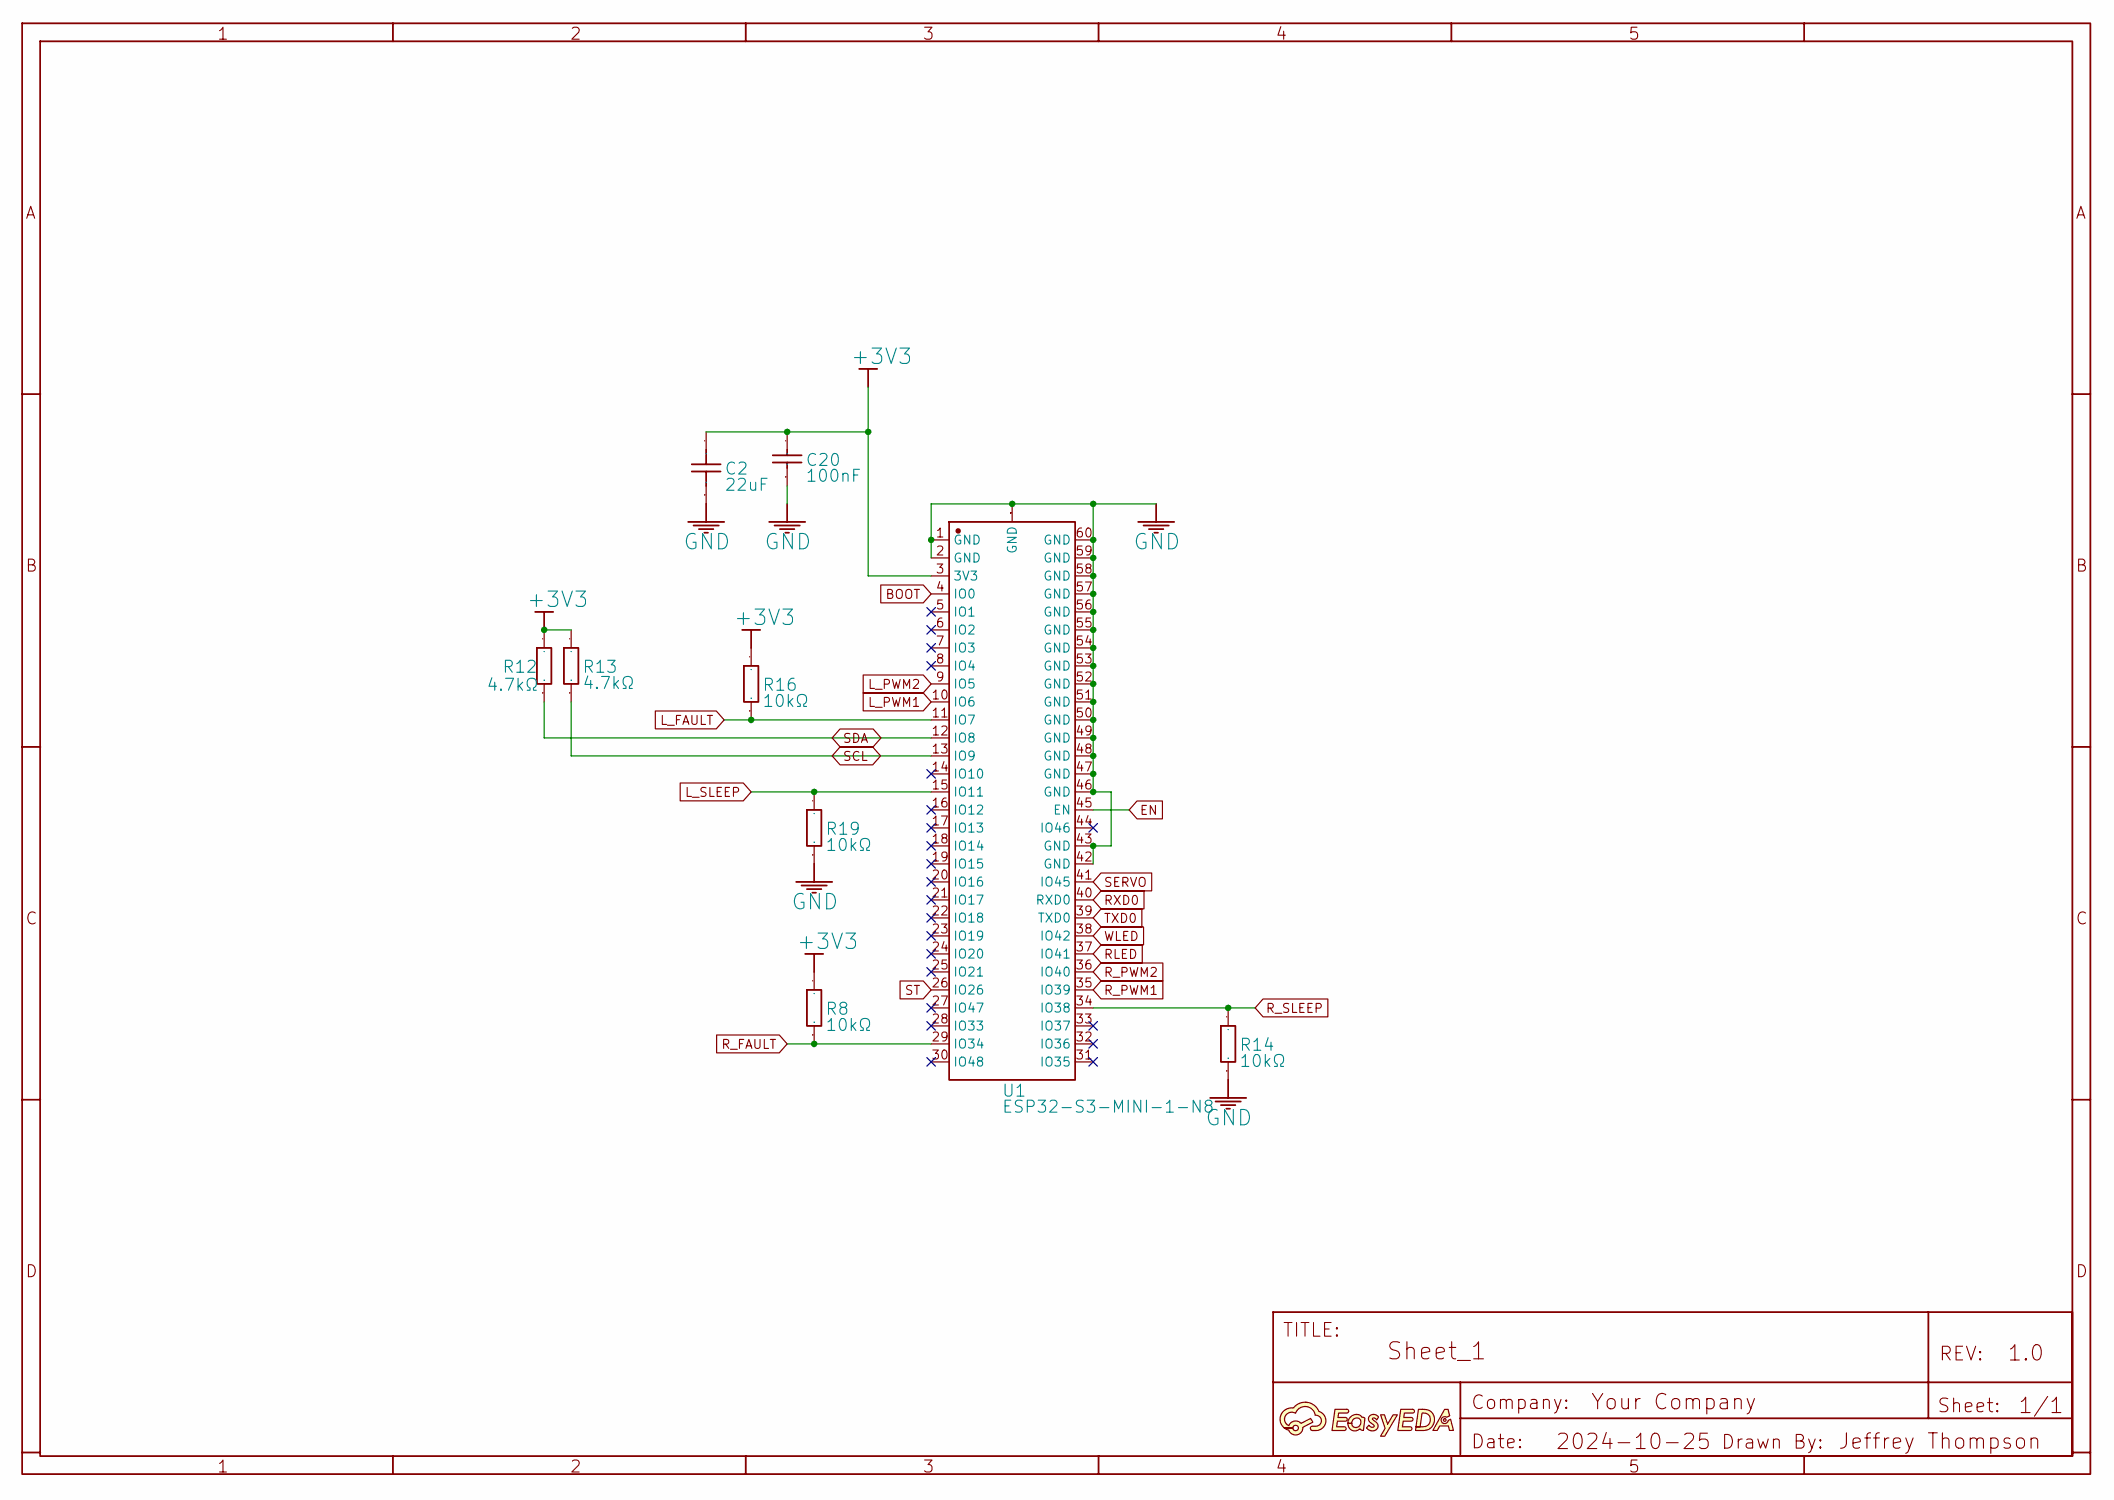
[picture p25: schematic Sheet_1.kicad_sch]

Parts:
A: A; Manufacturer Part ?
C2: 22uF; C0805; Manufacturer Part CL21A226MAQNNNE
C20: 100nF; C0402_NEW; Manufacturer Part CL05B104KO5NNNC
R8, R14, R16, R19: 10kΩ; R0402; Manufacturer Part 0402WGF1002TCE
R12, R13: 4.7kΩ; R0402; Manufacturer Part 0402WGF4701TCE
U1: ESP32-S3-MINI-1-N8; BULETM-SMD_ESP32-S3-MINI-1-N8; Manufacturer Part ESP32-S3-MINI-1-N8

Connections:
+3V3: C2.2, C20.2, R8.2, R12.2, R13.2, R16.2, U1.3 (3V3); also elsewhere on the board
BOOT: U1.4 (IO0); also elsewhere on the board
EN: U1.45 (EN); also elsewhere on the board
GND: C2.1, C20.1, R14.1, R19.1, U1.1 (GND), U1.2 (GND), U1.42 (GND), U1.43 (GND), U1.46 (GND), U1.47 (GND), U1.48 (GND), U1.49 (GND), U1.50 (GND), U1.51 (GND), U1.52 (GND), U1.53 (GND), U1.54 (GND), U1.55 (GND), U1.56 (GND), U1.57 (GND), U1.58 (GND), U1.59 (GND), U1.60 (GND), U1.GND; also elsewhere on the board
L_FAULT: R16.1, U1.11 (IO7); also elsewhere on the board
L_PWM1: U1.10 (IO6); also elsewhere on the board
L_PWM2: U1.9 (IO5); also elsewhere on the board
L_SLEEP: R19.2, U1.15 (IO11); also elsewhere on the board
RLED: U1.37 (IO41); also elsewhere on the board
RXD0: U1.40 (RXD0); also elsewhere on the board
R_FAULT: R8.1, U1.29 (IO34); also elsewhere on the board
R_PWM1: U1.35 (IO39); also elsewhere on the board
R_PWM2: U1.36 (IO40); also elsewhere on the board
R_SLEEP: R14.2, U1.34 (IO38); also elsewhere on the board
SCL: R13.1, U1.13 (IO9); also elsewhere on the board
SDA: R12.1, U1.12 (IO8); also elsewhere on the board
SERVO: U1.41 (IO45); also elsewhere on the board
ST: U1.26 (IO26); also elsewhere on the board
TXD0: U1.39 (TXD0); also elsewhere on the board
WLED: U1.38 (IO42); also elsewhere on the board

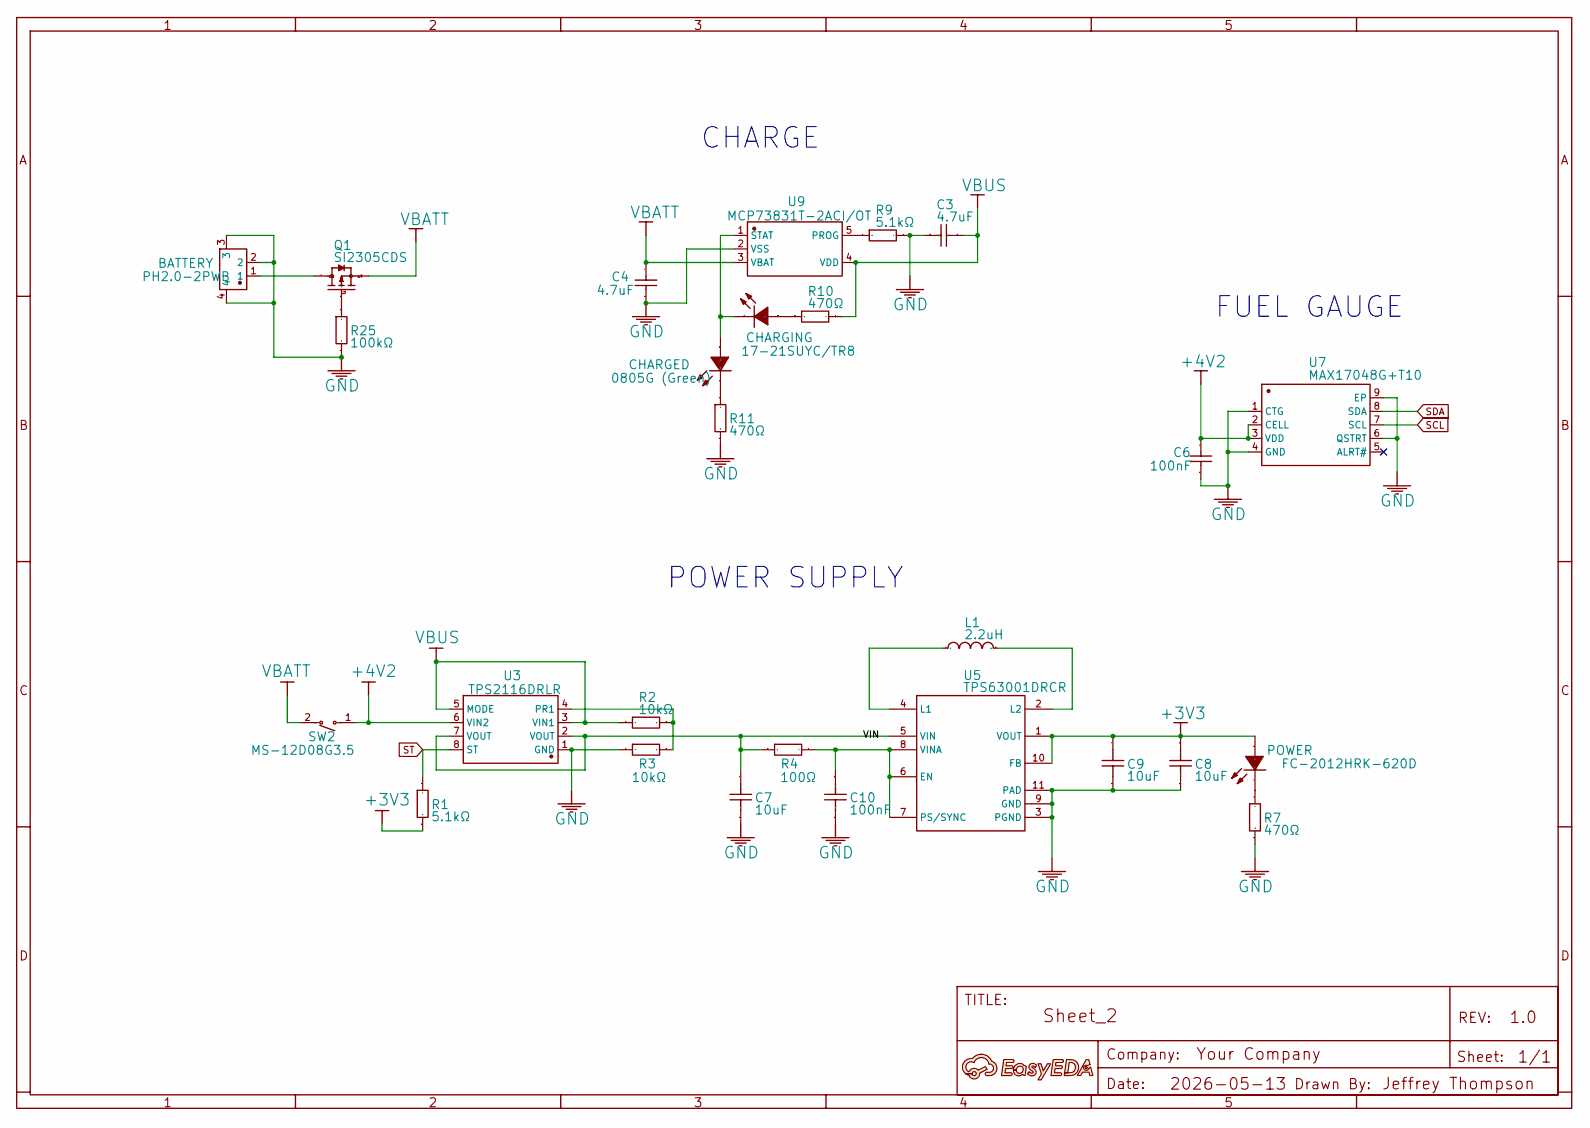
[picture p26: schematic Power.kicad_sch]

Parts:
A: A; Manufacturer Part ?
BATTERY: PH2.0-2PWB; CONN-SMD_2P-P2.00_PH2.0-SPWB; Manufacturer Part PH-2P卧贴
C3, C4: 4.7uF; C0805; Manufacturer Part CL21A475KAQNNNE
C6: 100nF; C0402_NEW; Manufacturer Part CL05B104KO5NNNC
C7, C8, C9: 10uF; C0603; Manufacturer Part CL10B106MQ8NRNC
C10: 100nF; C0402_v2; Manufacturer Part CL05B104KO5NNNC
CHARGED: 0805G (Green); LED0805-R-RD; Manufacturer Part KT-0805G
CHARGING: 17-21SUYC/TR8; LED0805-R-RD; Manufacturer Part KT-0805黄灯
L1: 2.2uH; IND-SMD_L3.0-W3.0_FNR30XXS; Manufacturer Part SPH3015H2R2MT
POWER: FC-2012HRK-620D; LED0805-R-RD; Manufacturer Part NCD0805R1
Q1: SI2305CDS; SOT-23-3_L2.9-W1.6-P1.90-LS2.8-BR; Manufacturer Part SI2305CDS
R1, R9: 5.1kΩ; R0402; Manufacturer Part 0402WGF5101TCE
R2, R3: 10kΩ; R0402; Manufacturer Part 0402WGF1002TCE
R4: 100Ω; R0402; Manufacturer Part 0402WGF1000TCE
R7, R10, R11: 470Ω; R0603; Manufacturer Part 0603WAF4700T5E
R25: 100kΩ; R0603; Manufacturer Part 0603WAF1003T5E
SW2: MS-12D08G3.5; SW-TH_MS-12D08G3.5; Manufacturer Part MS-12D08G3.5
U3: TPS2116DRLR; SOT-583-8_L2.1-W1.6-P0.50-LS1.6-BL; Manufacturer Part TPS2116DRLR
U5: TPS63001DRCR; VSON-10_L3.0-W3.0-P0.50-TL-EP_TPS62410DRCR; Manufacturer Part TPS63001DRCR
U7: MAX17048G+T10; TDFN-8_L2.0-W2.0-P0.50-BL-EP1.2; Manufacturer Part MAX17048G+T10
U9: MCP73831T-2ACI/OT; SOT-23-5_L3.0-W1.7-P0.95-LS2.8-BR; Manufacturer Part MCP73831T-2ACI/OT

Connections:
+3V3: C8.2, C9.2, POWER.1 (+), R1.1, U5.1 (VOUT), U5.10 (FB); also elsewhere on the board
+4V2: C6.2, SW2.1, U3.6 (VIN2), U7.2 (CELL), U7.3 (VDD); also elsewhere on the board
/Power/VIN: C7.2, R4.1, U3.2 (VOUT), U3.7 (VOUT), U5.5 (VIN)
GND: BATTERY.2, BATTERY.3, BATTERY.4, C3.1, C4.1, C6.1, C7.1, C8.1, C9.1, C10.1, R3.2, R7.1, R9.2, R11.1, R25.1, U3.1 (GND), U5.3 (PGND), U5.9 (GND), U5.11 (PAD), U7.1 (CTG), U7.4 (GND), U7.6 (QSTRT), U7.9 (EP), U9.2 (VSS); also elsewhere on the board
unnamed: CHARGED.1 (A), CHARGING.2 (-), U9.1 (STAT)
unnamed: CHARGED.2 (K), R11.2
unnamed: CHARGING.1 (+), R10.1
unnamed: POWER.2 (-), R7.2
unnamed: BATTERY.1, Q1.3 (D)
unnamed: Q1.1 (G), R25.2
unnamed: R2.1, R3.1, U3.4 (PR1)
unnamed: C10.2, R4.2, U5.6 (EN), U5.7 (PS/SYNC), U5.8 (VINA)
unnamed: L1.2, U5.4 (L1)
unnamed: L1.1, U5.2 (L2)
unnamed: R9.1, U9.5 (PROG)
SCL: U7.7 (SCL); also elsewhere on the board
SDA: U7.8 (SDA); also elsewhere on the board
ST: R1.2, U3.8 (ST); also elsewhere on the board
VBATT: C4.2, Q1.2 (S), SW2.2, U9.3 (VBAT)
VBUS: C3.2, R2.2, R10.2, U3.3 (VIN1), U3.5 (MODE), U9.4 (VDD); also elsewhere on the board

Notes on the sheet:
FUEL GAUGE
POWER SUPPLY
CHARGE

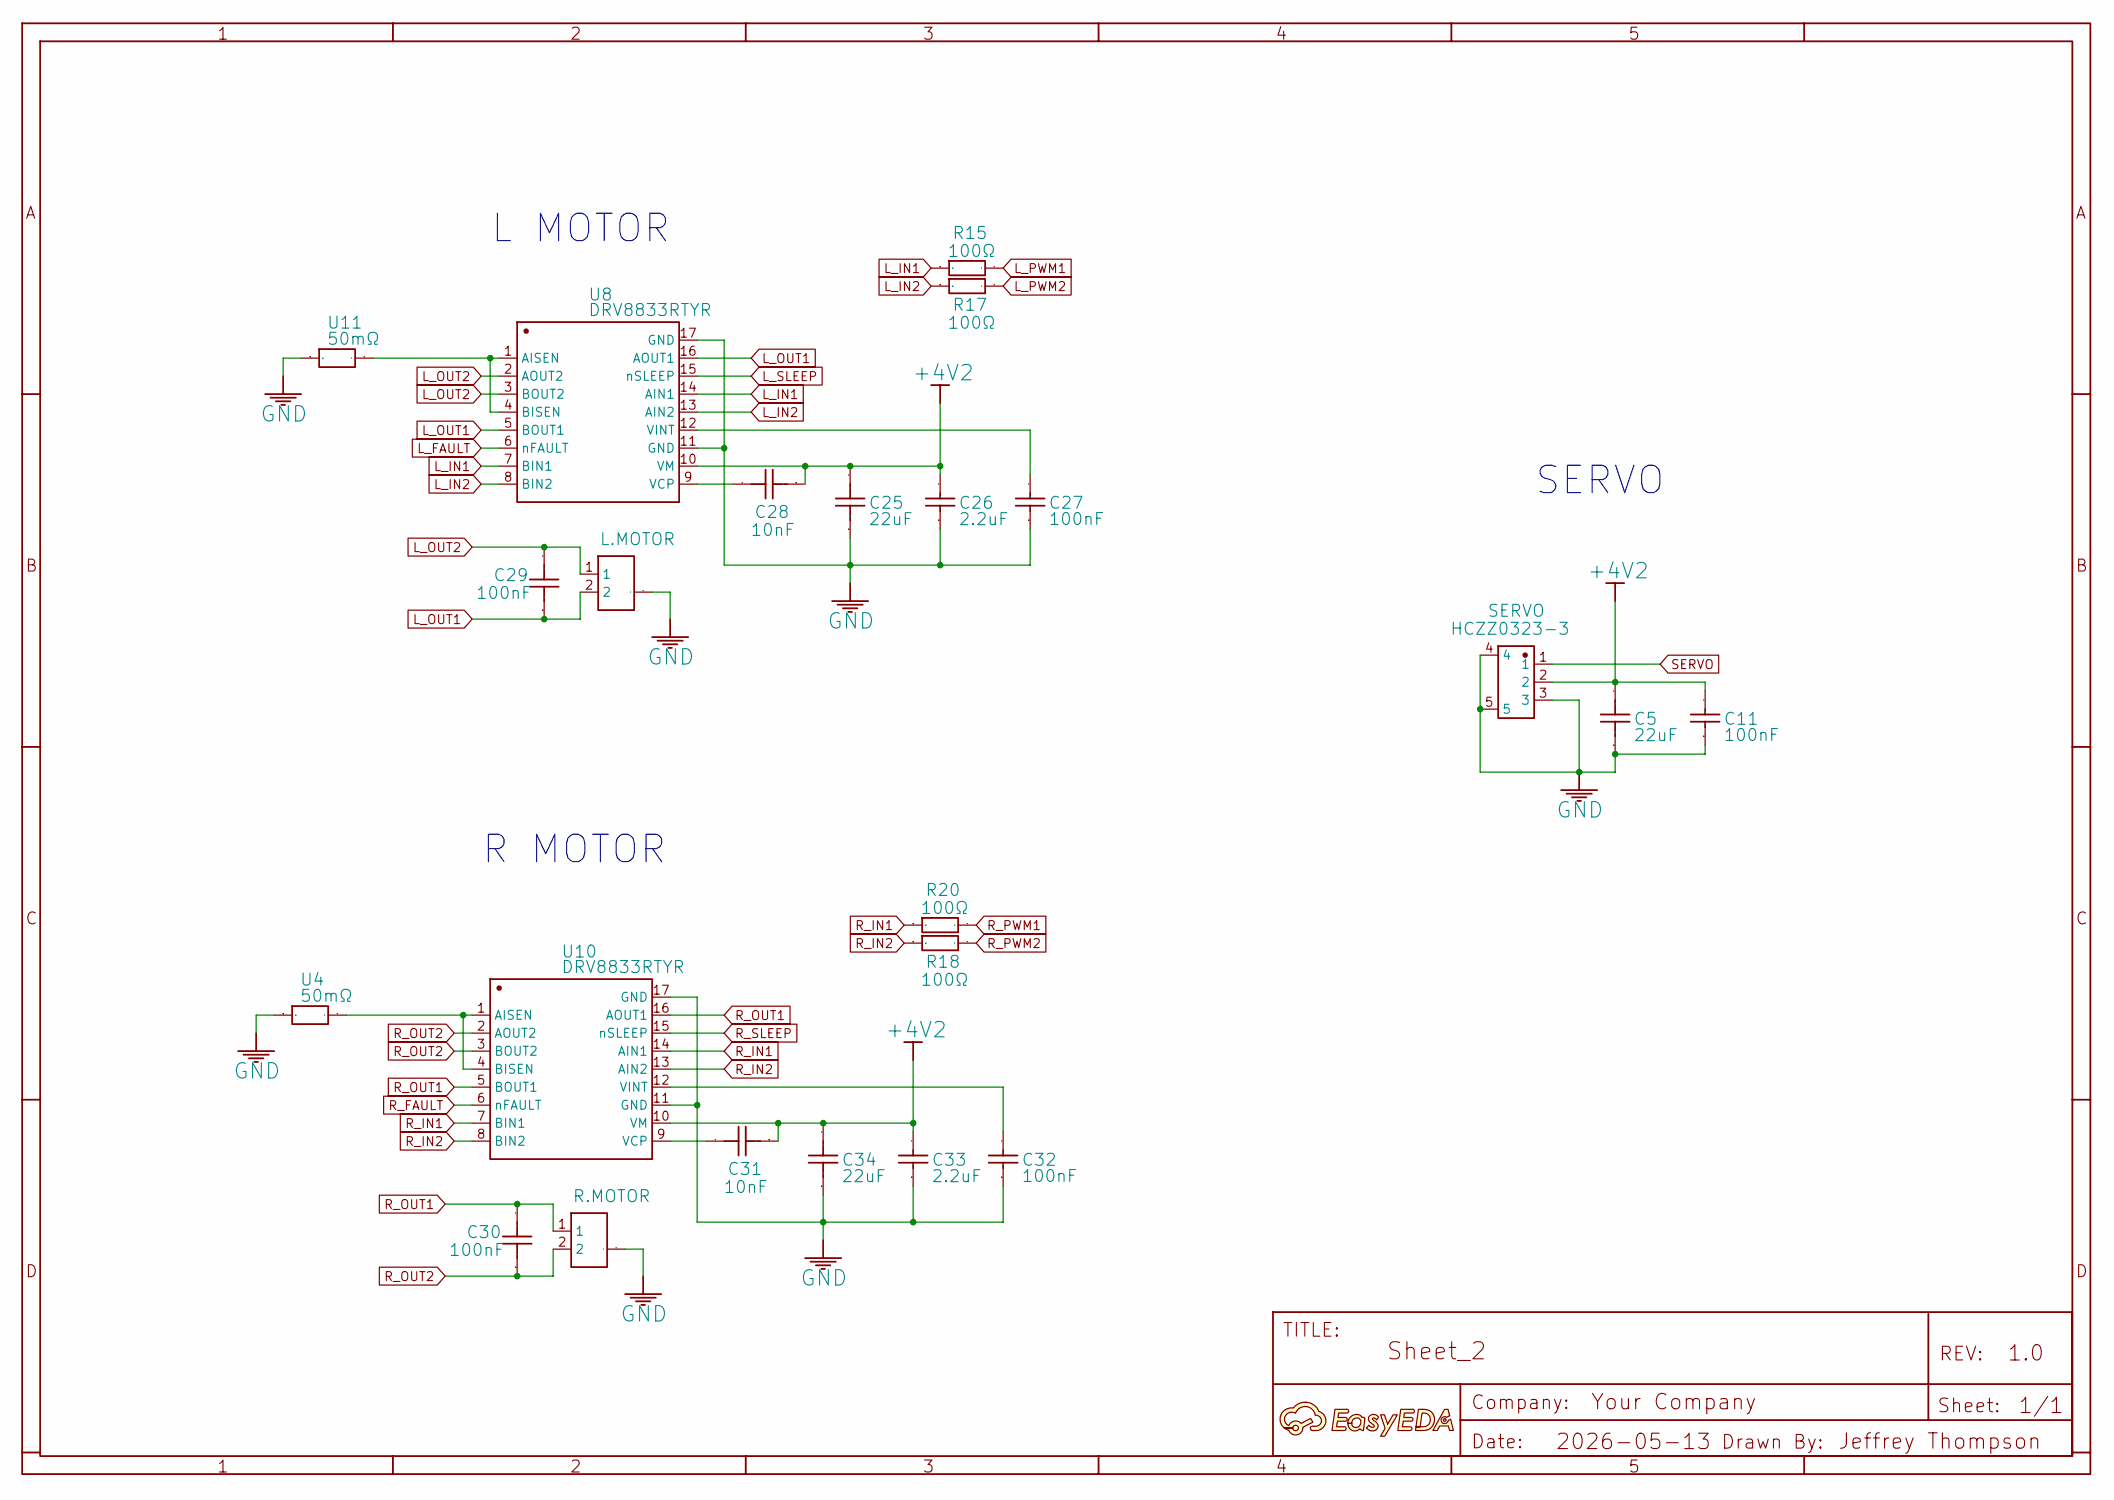
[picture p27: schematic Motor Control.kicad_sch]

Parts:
A: A; Manufacturer Part ?
C5, C25, C34: 22uF; C1206; Manufacturer Part HGC1206R7226K160NSPJ
C11, C27, C32: 100nF; C0603; Manufacturer Part CL10B104KO8NNNC
C26, C33: 2.2uF; C0603; Manufacturer Part CL10B225KP8NNNC
C28, C31: 10nF; C0603; Manufacturer Part CC0603KRX7R7BB103
C29, C30: 100nF; C0603; Manufacturer Part CC0603KRX7R9BB104
L.MOTOR: S2B-ZR-SM4A-TF(LF)(SN); CONN-SMD_S2B-ZR-SM4A; Manufacturer Part S2B-ZR-SM4A-TF(LF)(SN)
R15, R17, R18, R20: 100Ω; R0402; Manufacturer Part RC0402FR-07100RL
R.MOTOR: S2B-ZR-SM4A-TF(LF)(SN); CONN-SMD_S2B-ZR-SM4A; Manufacturer Part S2B-ZR-SM4A-TF(LF)(SN)
SERVO: HCZZ0323-3; CONN-SMD_3P-P1.50_HCZZ0323-3; Manufacturer Part HCZZ0323-3
U4, U11: 50mΩ; R1206; Manufacturer Part FRM121WFR050TM
U8, U10: DRV8833RTYR; QFN-16_L4.0-W4.0-P0.65-TL-EP2.6; Manufacturer Part DRV8833RTYR

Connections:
+4V2: C5.2, C11.2, C25.2, C26.2, C28.1, C31.1, C33.2, C34.2, SERVO.2, U8.10 (VM), U10.10 (VM); also elsewhere on the board
GND: C5.1, C11.1, C25.1, C26.1, C27.1, C32.1, C33.1, C34.1, L.MOTOR.0, R.MOTOR.0, SERVO.3, SERVO.4, SERVO.5, U4.1, U8.11 (GND), U8.17 (GND), U10.11 (GND), U10.17 (GND), U11.1; also elsewhere on the board
L_FAULT: U8.6 (nFAULT); also elsewhere on the board
L_IN1: R15.1, U8.7 (BIN1), U8.14 (AIN1)
L_IN2: R17.1, U8.8 (BIN2), U8.13 (AIN2)
L_OUT1: C29.1, L.MOTOR.2, U8.5 (BOUT1), U8.16 (AOUT1)
L_OUT2: C29.2, L.MOTOR.1, U8.2 (AOUT2), U8.3 (BOUT2)
L_PWM1: R15.2; also elsewhere on the board
L_PWM2: R17.2; also elsewhere on the board
L_SLEEP: U8.15 (nSLEEP); also elsewhere on the board
unnamed: U8.1 (AISEN), U8.4 (BISEN), U11.2
unnamed: C28.2, U8.9 (VCP)
unnamed: C27.2, U8.12 (VINT)
unnamed: U4.2, U10.1 (AISEN), U10.4 (BISEN)
unnamed: C31.2, U10.9 (VCP)
unnamed: C32.2, U10.12 (VINT)
R_FAULT: U10.6 (nFAULT); also elsewhere on the board
R_IN1: R20.1, U10.7 (BIN1), U10.14 (AIN1)
R_IN2: R18.1, U10.8 (BIN2), U10.13 (AIN2)
R_OUT1: C30.2, R.MOTOR.1, U10.5 (BOUT1), U10.16 (AOUT1)
R_OUT2: C30.1, R.MOTOR.2, U10.2 (AOUT2), U10.3 (BOUT2)
R_PWM1: R20.2; also elsewhere on the board
R_PWM2: R18.2; also elsewhere on the board
R_SLEEP: U10.15 (nSLEEP); also elsewhere on the board
SERVO: SERVO.1; also elsewhere on the board

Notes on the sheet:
SERVO
R MOTOR
L MOTOR

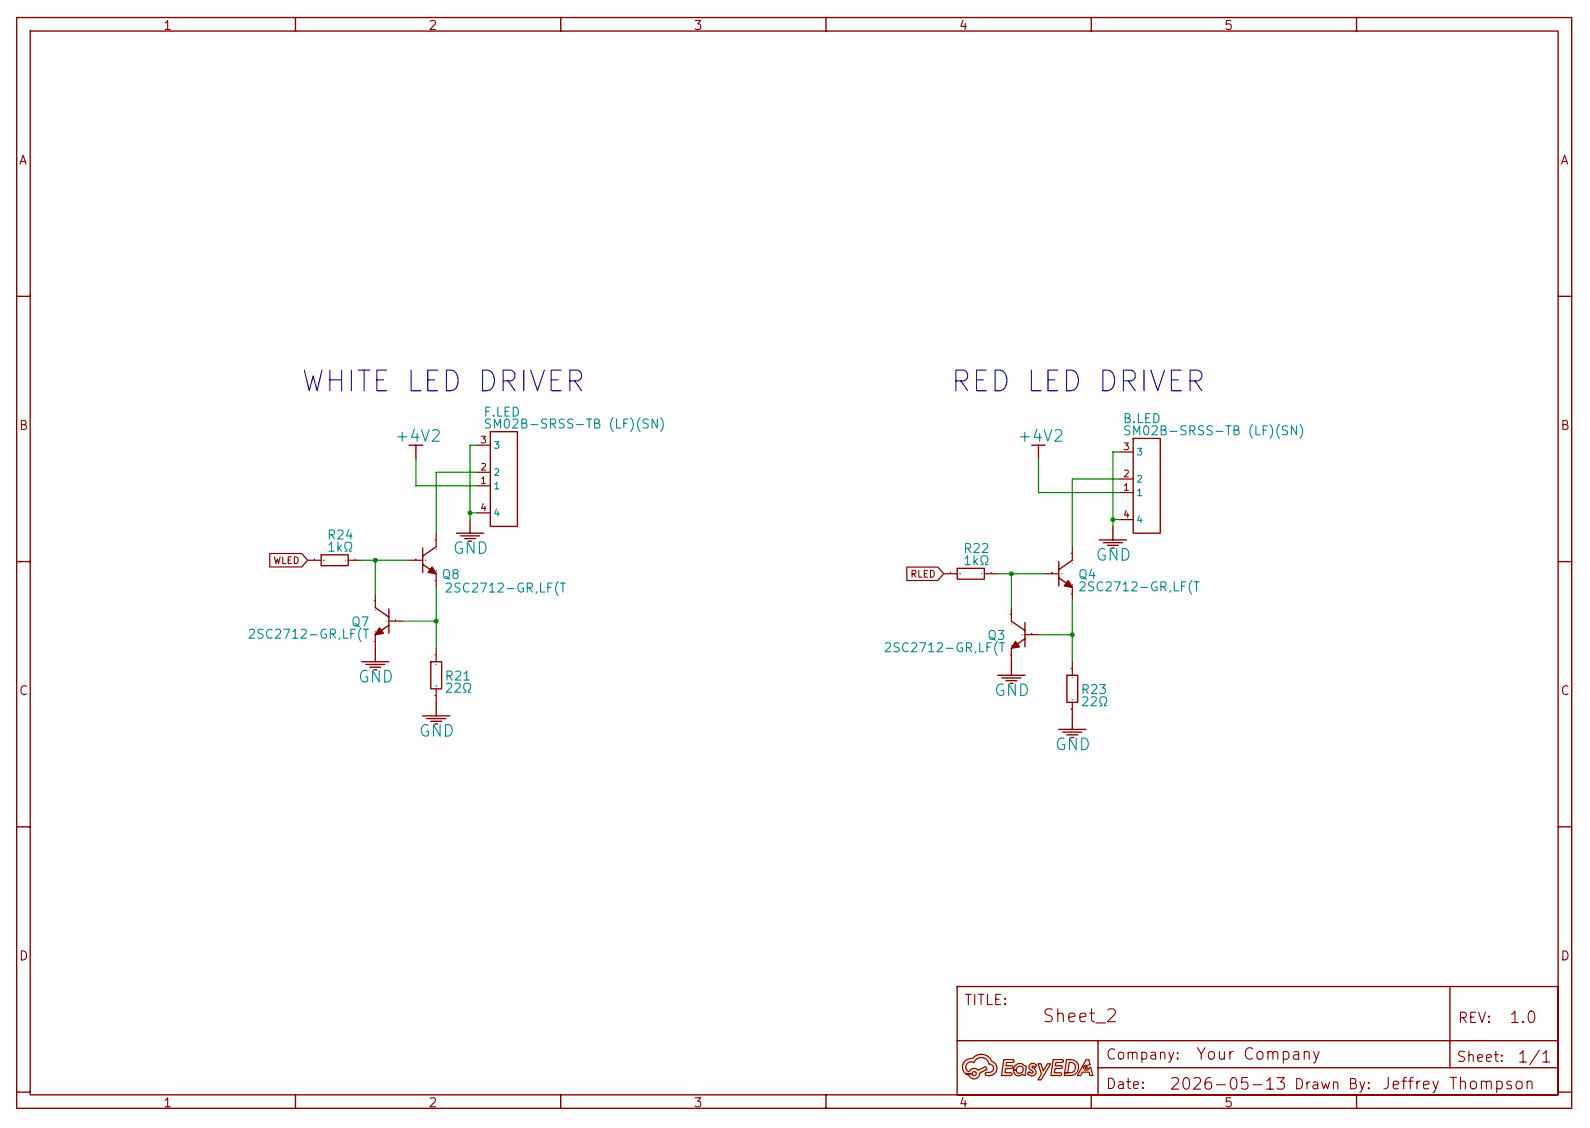
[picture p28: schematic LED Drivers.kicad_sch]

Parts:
A: A; Manufacturer Part ?
B.LED: SM02B-SRSS-TB (LF)(SN); CONN-SMD_2P-P1.00_SM02B-SRSS-TB-LF-SN; Manufacturer Part SM02B-SRSS-TB(LF)(SN)
F.LED: SM02B-SRSS-TB (LF)(SN); CONN-SMD_2P-P1.00_SM02B-SRSS-TB-LF-SN; Manufacturer Part SM02B-SRSS-TB(LF)(SN)
Q3, Q4, Q7, Q8: 2SC2712-GR,LF(T; SOT-23-3_L2.9-W1.6-P1.90-LS2.8-BR; Manufacturer Part 2SC2712-GR,LF(T
R21, R23: 22Ω; R0603; Manufacturer Part 0603WAF220JT5E
R22, R24: 1kΩ; R0603; Manufacturer Part MCT06030C1001FP500

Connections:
+4V2: B.LED.1, F.LED.1; also elsewhere on the board
GND: B.LED.3, B.LED.4, F.LED.3, F.LED.4, Q3.2 (E), Q7.2 (E), R21.1, R23.1; also elsewhere on the board
unnamed: Q3.1 (B), Q4.2 (E), R23.2
unnamed: Q3.3 (C), Q4.1 (B), R22.2
unnamed: B.LED.2, Q4.3 (C)
unnamed: Q7.1 (B), Q8.2 (E), R21.2
unnamed: Q7.3 (C), Q8.1 (B), R24.2
unnamed: F.LED.2, Q8.3 (C)
RLED: R22.1; also elsewhere on the board
WLED: R24.1; also elsewhere on the board

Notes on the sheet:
RED LED DRIVER
WHITE LED DRIVER

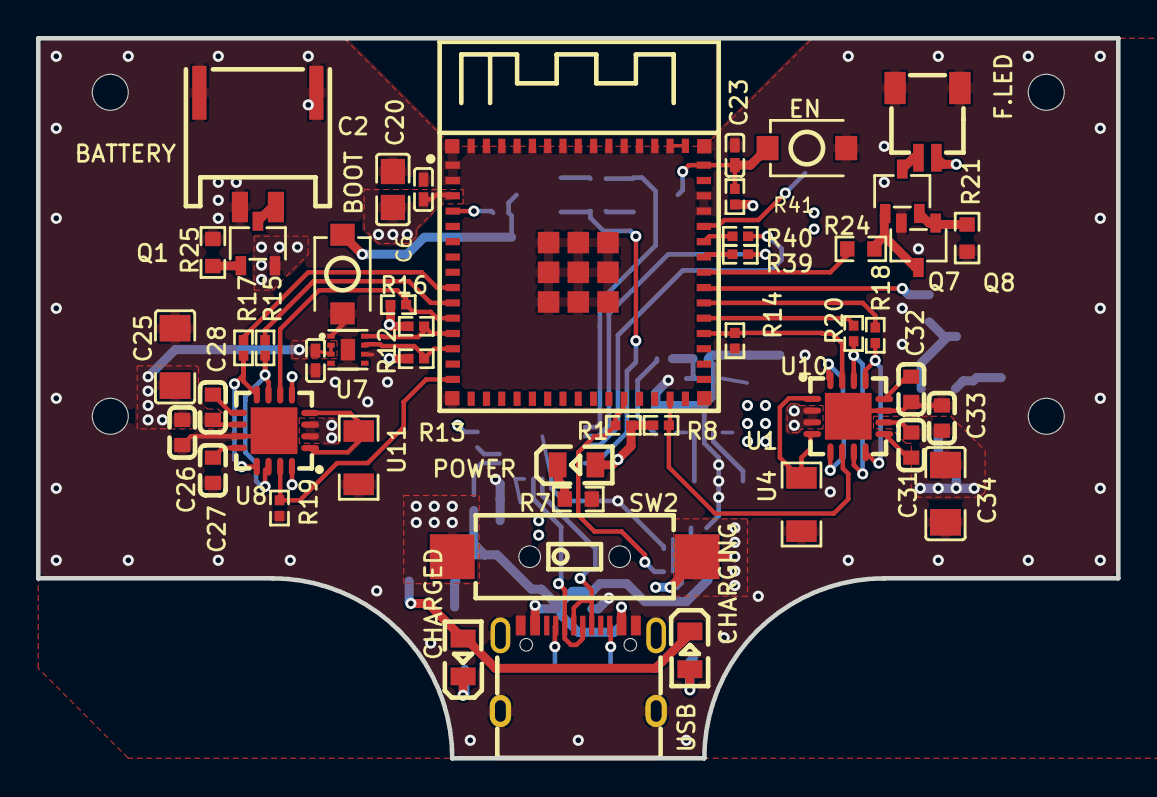
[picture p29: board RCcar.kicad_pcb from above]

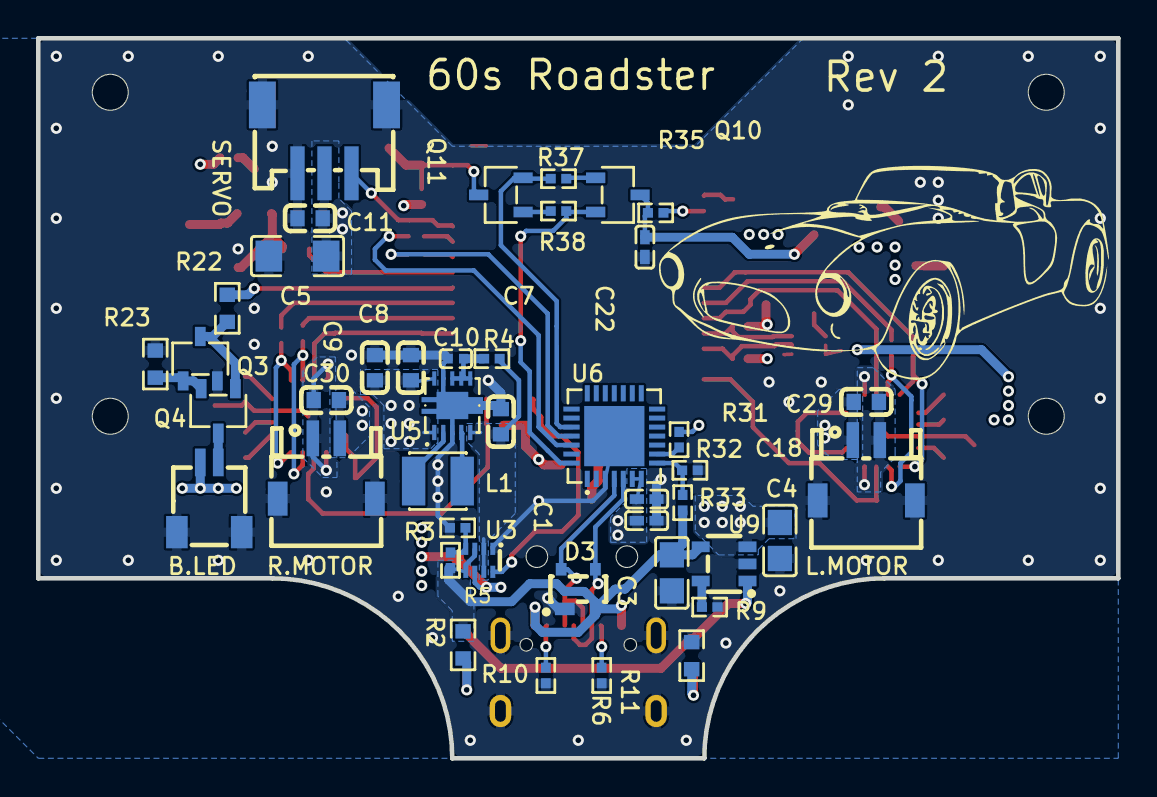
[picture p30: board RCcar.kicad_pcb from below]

Board: 4 copper layers, 60.0 x 40.0 mm, 95 parts (43 on the bottom side), 68 nets.

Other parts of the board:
Hole_gge8842846562267455: Hole_gge8842846562267455
Hole_gge8842846562267458: Hole_gge8842846562267458
Hole_gge8842846562267461: Hole_gge8842846562267461
Hole_gge8842846562267464: Hole_gge8842846562267464

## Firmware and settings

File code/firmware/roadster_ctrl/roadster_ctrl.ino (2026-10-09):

#include "SteeringModule.h"
#include "DriveModule.h"
#include "BatteryModule.h"
#include "LightsModule.h"
#include "SerialCommander.h"
#include "BleCommander.h"

// Hardware Configuration
const int PIN_SERVO = 45;

// Left Motor (DRV8833)
const int PIN_MOTOR_LEFT_A = 6;
const int PIN_MOTOR_LEFT_B = 5;

// Right Motor (DRV8833)
const int PIN_MOTOR_RIGHT_A = 39;
const int PIN_MOTOR_RIGHT_B = 40;

// DRV8833 Control
const int PIN_L_SLEEP = 11;
const int PIN_R_SLEEP = 38;
const int PIN_L_FAULT = 7;
const int PIN_R_FAULT = 34;

// Battery I2C
const int PIN_I2C_SDA = 8;
const int PIN_I2C_SCL = 9;

// Power status: TPS2116 ST output (HIGH = USB power, LOW = battery)
const int PIN_POWER_ST = 26;

// Lights (F.LED and B.LED connectors)
const int PIN_WLED = 42; // front / headlights
const int PIN_RLED = 41; // rear / tail + brake

const bool ENABLE_SERIAL = false;
const bool ENABLE_STEERING = true;
const bool ENABLE_DRIVE = true;

// Global Objects
SteeringModule steering(PIN_SERVO);
DriveModule driveLeft(PIN_MOTOR_LEFT_A, PIN_MOTOR_LEFT_B, PIN_L_SLEEP, PIN_L_FAULT);
DriveModule driveRight(PIN_MOTOR_RIGHT_A, PIN_MOTOR_RIGHT_B, PIN_R_SLEEP, PIN_R_FAULT);
BatteryModule battery(PIN_I2C_SDA, PIN_I2C_SCL, PIN_POWER_ST);
LightsModule lights(PIN_WLED, PIN_RLED);

// Control Interfaces
SerialCommander serialCmd(steering, driveLeft, driveRight);
BleCommander bleCmd(steering, driveLeft, driveRight, battery, lights);

void setup() {
  // Initialize Modules
  // Steering must attach first: ESP32Servo claims LEDC channel 0 directly,
  // and analogWrite() would otherwise have handed that channel to the lights,
  // leaving the servo and headlights sharing one PWM signal.
  if (ENABLE_STEERING) {
    steering.begin();
  }

  lights.begin();

  if (ENABLE_DRIVE) {
    driveLeft.begin();
    driveRight.begin();
  }

  battery.begin();
  
  // Correct for wiring: Left motor is physically reversed relative to Right
  if (ENABLE_DRIVE) {
    driveLeft.setInverted(true);
    driveRight.setInverted(true);
  }
  
  // Initialize Serial Commander
  if (ENABLE_SERIAL) {
    serialCmd.begin(115200);
  }

  // Initialize BLE Commander
  bleCmd.begin("Open Roadster");
}

void loop() {
  if (ENABLE_SERIAL) {
    serialCmd.update();
  }
  bleCmd.update();

  battery.update();
  lights.update();
}

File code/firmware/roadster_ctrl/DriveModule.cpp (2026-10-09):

#include "DriveModule.h"

DriveModule::DriveModule(int pinA, int pinB, int pinSleep, int pinFault) {
  _pinA = pinA;
  _pinB = pinB;
  _pinSleep = pinSleep;
  _pinFault = pinFault;
  _inverted = false;
}

void DriveModule::begin() {
  pinMode(_pinA, OUTPUT);
  pinMode(_pinB, OUTPUT);
  setSpeed(0);

  if (_pinSleep >= 0) {
    pinMode(_pinSleep, OUTPUT);
    digitalWrite(_pinSleep, LOW);
  }

  if (_pinFault >= 0) {
    pinMode(_pinFault, INPUT);
  }

  if (_pinSleep >= 0) {
    digitalWrite(_pinSleep, HIGH);
    delay(2);
  }
}

void DriveModule::setInverted(bool inverted) {
  _inverted = inverted;
}

void DriveModule::setSleep(bool enabled) {
  if (_pinSleep < 0) {
    return;
  }

  digitalWrite(_pinSleep, enabled ? HIGH : LOW);
  if (enabled) {
    delay(2);
  }
}

bool DriveModule::isFaulted() const {
  if (_pinFault < 0) {
    return false;
  }

  return digitalRead(_pinFault) == LOW;
}

void DriveModule::setSpeed(int speed) {
  // Apply inversion if enabled
  if (_inverted) {
    speed = -speed;
  }

  // Constrain speed to valid PWM range
  int safeSpeed = constrain(speed, -255, 255);

  if (safeSpeed > 0) {
    // Forward
    analogWrite(_pinA, safeSpeed);
    analogWrite(_pinB, 0);
  } else if (safeSpeed < 0) {
    // Backward
    analogWrite(_pinA, 0);
    analogWrite(_pinB, -safeSpeed); // Convert to positive for PWM duty cycle
  } else {
    // Stop / Brake
    analogWrite(_pinA, 0);
    analogWrite(_pinB, 0);
  }
}

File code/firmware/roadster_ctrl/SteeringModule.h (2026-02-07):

#ifndef STEERING_MODULE_H
#define STEERING_MODULE_H

#include <Arduino.h>
#include <ESP32Servo.h>

class SteeringModule {
  public:
    SteeringModule(int pin);
    void begin();
    void setSteering(int usec);
    
    // Constants from original servo.ino
    static const int SERVO_USEC_MIN = 900;
    static const int SERVO_USEC_MAX = 2100;
    static const int SERVO_CENTER = 1520;
    static const int SERVO_FREQ = 333;

  private:
    int _pin;
    Servo _servo;
};

#endif

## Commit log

2026-01-23 commit printed parts
2026-02-06 3d model insert size edit. stub out firmware servo module
2026-02-07 fix motor inversion
2026-07-14 cleaned up blender file
    [roadster.blend]
2026-10-09 Import ESP32-S3 firmware and fix BLE failsafe
    Bring in the current firmware (ESP32-S3, DRV8833 drivers, MAX17048 fuel
    gauge, binary control packet + battery service) that was only on another
    machine, replacing the stale ESP32-C3 code.
    - Drop queued packets on disconnect so the car can't drive off on a stale
    command after the failsafe stop
    - Mark BLE-task/loop shared flags volatile
    - Use setMaxPreferred for the second connection parameter
    - esp-flash.sh: portable shebang, real arduino-cli check, target esp32s3
    [BatteryModule.cpp, BleCommander.cpp, DriveModule.cpp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]
2026-10-09 Update README for current hardware and add LICENSE
    Document the ESP32-S3 pinout, BLE protocol, firmware build steps, and the
    iOS app. License code under MIT and hardware designs under CC BY 4.0.
2026-10-09 Add FreeCAD chassis models converted from Onshape
    Export the or.assy assembly and every or.* part (plus PCB) from Onshape
    and convert to FreeCAD, split into Printed, Purchased, and Sheet Metal
    Parts. The steel chassis base also gets a flat-pattern DXF (CUT/BEND
    layers) and a bent STEP for ordering from a sheet metal shop.
    [OpenRoadster.FCStd, PCB.FCStd, or.bearing.front.FCStd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]
2026-10-09 Add controller PCB from EasyEDA
    Export the RCcar EasyEDA Standard project: schematic and PCB source,
    a schematic PDF, and JLCPCB fabrication files (Gerbers, BOM with LCSC
    part numbers, pick-and-place). Document the board in the README.
    [RCcar_bom.csv, RCcar_pick_and_place.csv]
2026-10-09 Port controller PCB to KiCad 10
    Import the EasyEDA schematic and board into a self-contained KiCad project
    with project symbol and footprint libraries, and verify it against the
    EasyEDA original:
    - Restore 6 schematic connections the importer split (local vs global
    labels for SDA/SCL/TXD0/RXD0/EN, a missing +4V2 junction)
    - Add 14 short tracks where KiCad's pour fill missed fine-pitch pins that
    EasyEDA's pour connected; 0 unconnected items, 0 clearance errors
    - Restore solder paste on 171 pads, drop imported keepouts, fix text fonts
    - Match EasyEDA design rules; schematic/board parity is clean
    - Move component values off the silkscreen; only designators are printed
    Remaining DRC items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
    [LED Drivers.kicad_sch, Motor Control.kicad_sch, Power.kicad_sch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]
2026-10-09 Add JLCPCB order files generated from KiCad
    Gerbers and drill files, BOM with LCSC part numbers, and CPL in JLCPCB's
    format. Checked against the EasyEDA exports: same 91 parts and LCSC
    numbers, identical positions, sides and rotations, copper within ~1%.
    [RCcar_bom_jlcpcb.csv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]
2026-10-09 Update FreeCAD chassis assembly; ignore FreeCAD backups
    [OpenRoadster.FCStd]
2026-10-09 Add tail/brake light and USB power status to firmware
    - New LightsModule drives the front (GPIO 42) and rear (GPIO 41) lights
    with PWM: headlights on gives a dim tail light; releasing the throttle,
    a sharp drop, or reversing turns the rear light into a brake light
    - BatteryModule reads the TPS2116 ST output (GPIO 26) to report USB power
    vs battery, flagging changes immediately
    - New Power Source characteristic in the battery service
    (8FDDF80E-8D10-4B50-9466-FCE56AF3B124): 1 = USB/charging, 0 = battery
    [BatteryModule.cpp, BleCommander.cpp, LightsModule.cpp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]
2026-10-09 Show charging indicator in iOS app
    Subscribe to the car's Power Source characteristic and show a lightning
    bolt in the fuel gauge while the car is on USB power (battery charging).
2026-10-09 Fix servo and headlights sharing a PWM channel
    ESP32Servo claims LEDC channel 0 directly, but lights.begin() ran first
    and analogWrite() had already given channel 0 to the headlights. The
    servo then got the 1 kHz light signal and the headlights followed the
    servo duty, so they never turned off. Attach steering before the lights.
    [roadster_ctrl.ino]
2026-10-10 Add TODO with battery protection plan and open items
2026-10-10 Add printable STLs, make KiCad order files canonical, tidy app settings
    - Export the 14 printed parts to mechanical/stl/ (watertight, volumes match CAD)
    - Move the KiCad JLCPCB files up to circuits/fabrication/ and archive the
    EasyEDA order files under circuits/easyeda/fabrication/
    - Remove the old servo test sketch (pins for a different ESP32)
    - iOS app: org.openroadster bundle ID, real Bluetooth/motion permission
    text, deployment target 18.0 throughout
    [RCcar_bom.csv, RCcar_bom_jlcpcb.csv, RCcar_pick_and_place.csv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]
2026-10-13 Scale app throttle to the firmware's full PWM range
    The throttle stick runs 0..100 but the firmware treats the value as motor
    PWM (-255..255), so the app never drove the motors past ~39% duty. Scale
    the stick to 0..255 when building the packet, negated in Reverse.
    Also record the measured 82 mA idle current in the TODO.
2026-10-16 Split the README by discipline
    The main README is now a short landing page that links to a README in
    each folder: mechanical, circuits, firmware and app. Adds a Next steps
    note about a soft power switch so the car can't be left on to drain the
    LiPo, with the matching hardware item in the TODO.
2026-10-16 Return to the car list when the connection drops
    ConnectionState gains disconnecting and lost cases, so the app can tell
    a dropped connection from one the user ended. On lost, ContentView
    switches its Screen enum back to the car picker, and the car reappears
    under Nearby once it's back in range. The app shifts to Park in every
    state except connected.
2026-10-16 Credit the Open Source Hardware logo
    The blueprint image carries the open source hardware gear logo. Credit
    its designer and license, and note that the project isn't OSHWA
    certified.
2026-10-16 Add a photo of the car and switch the blueprint to JPEG
    The README now opens with a photo of the finished car above the
    blueprint. The blueprint image is a JPEG to save space.
2026-10-16 Add low-battery cutoff and a control-packet watchdog to the firmware
    Low-battery cutoff, using the MAX17048 cell voltage:
    - below 3.4 V: throttle limited to half, rear light blinks
    - below 3.2 V: motors stop, lights flash a warning, and the ESP32 goes
    into deep sleep with the motor, servo and light pins held low
    - while asleep it wakes every 60 s and stays asleep until it's on USB
    power or the cell has recovered above 3.6 V
    Each step needs three consecutive readings, and the state resets on USB
    power. Tested on USB and a bench supply; not yet on a real battery
    discharging to the thresholds.
    Bluetooth control:
    - The motors stop if no control packet arrives for 500 ms while the link
    is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
2026-10-16 Stream control packets at 20 Hz and stop the car in Park
    - Park sent nothing, so the car kept its last throttle. It now sends
    throttle 0, which also lets the headlights work in Park.
    - Packets go out on a 20 Hz timer instead of only when the phone's tilt
    updates, so throttle changes reach the car within 50 ms and the
    firmware's 500 ms watchdog stays fed.
    - Writes are without response when the car supports it. With older
    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
